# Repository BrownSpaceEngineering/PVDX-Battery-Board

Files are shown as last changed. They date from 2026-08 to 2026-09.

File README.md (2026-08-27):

# Battery-Board

Battery subsystem board for PVDX — connects the battery stack, solar cells/solar PCB, heaters, and thermistors.

## Status
- Design phase: fabrication
- Current rev: rev-1.1
- Contributors: Jayla Hsiung, Kelly Lin, Finn Kehoe, Dean Zweiman

## System overview

The Battery Board is primarily structural/routing rather than active. It has no onboard charging or regulation ICs (that logic lives on EPS). Its job is to tie the battery stack into the rest of the power subsystem: routing to the regular (non-perovskite) solar cells and solar PCB, driving the battery heaters, and carrying thermistor signals back for battery temperature monitoring.

**Board sheets:**

- **Heater**: battery heater circuit.
- **Connectors**: harness/pinout for battery, solar, heater, and thermistor connections. These are being hardwired rather than connectorized — the footprints (pad patterns) stay on the board for wire attachment points, but the 3D models are hidden (Show unchecked in Footprint Properties → 3D Models) so they don't appear in the STEP export.

### Repo layout

```
PVDX-Battery-Board/
├── PVDX-Battery-Board.kicad_pro / .kicad_sch / .kicad_pcb
├── fp-lib-table
├── schematics/
│   ├── heater.kicad_sch
│   └── connectors.kicad_sch
├── libs/
│   ├── footprints.pretty/
│   ├── symbols/
│   └── 3d_models/
└── manufacturing/
    └── rev-<N>_<date>/
        ├── gerbers/
        ├── bom/
        └── plots/
```

**Why hardwire instead of connectors:** simplifies the harness at the battery/heater interface and removes a failure point (connector) from a joint that doesn't need to be serviceable in flight. KiCad has no dedicated "exclude from STEP" option, so per-footprint 3D model visibility is the mechanism used to keep the pad pattern without the connector body in mechanical exports.

## Key design notes

- **Thermistor (NXFT15XV103FEAB025):** custom footprint, kept in `libs/footprints.pretty/`. The original vendor export had a stray space in the filename — fixed during the repo reorg.
- **Connector footprints, 3D models hidden:** see above — keep an eye on this after any "Update PCB from Schematic" footprint refresh, which can reset visibility to the library default and re-show the model.
- **`PVDX_BatteryBoard_Board.kicad_sch`** was an orphaned, blank sheet not referenced anywhere in the hierarchy — deleted during the reorg.

## Manufacturing history
| Rev | Date | Notes | Location |
|-----|---|---|---|
| 1.1 | 8/22/26 | Current gerber set | `manufacturing/rev-1.1_2026-08-22/` |

## Open items
- Fill in BOM for rev-1.1 (`manufacturing/rev-1.1_2026-08-22/bom/` currently empty)

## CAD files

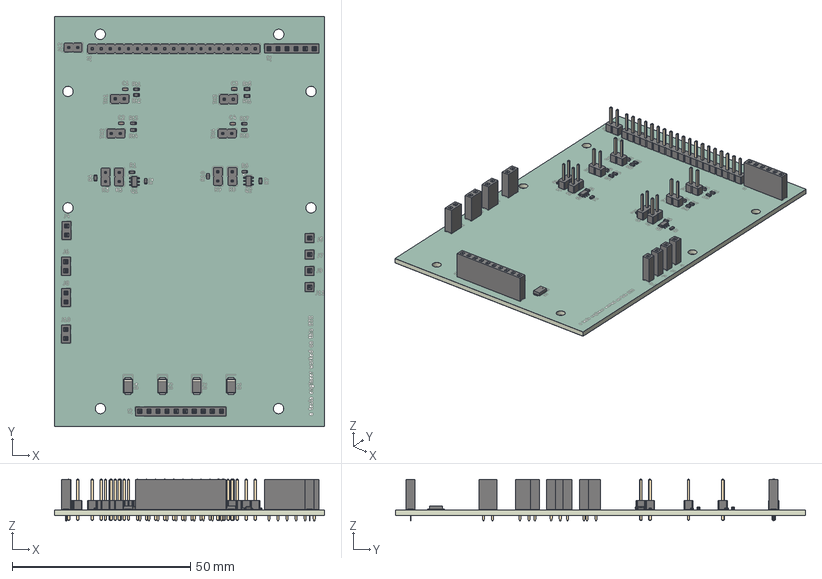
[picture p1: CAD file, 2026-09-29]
PVDX-Battery-Board.step
75.7 x 115.0 x 11.6 mm
R_0603_1608Metric x 14
PinSocket_1x01_P2.54mm_Vertical x 4
C_0603_1608Metric x 4
PinHeader_1x02_P2.54mm_Vertical x 9
PinSocket_1x10_P2.54mm_Vertical
D_SOD-128 x 4
PinSocket_1x06_P2.54mm_Vertical
PinHeader_1x19_P2.54mm_Vertical
PinSocket_1x02_P2.54mm_Vertical x 4
TSOT-23-6 x 2
PVDX_BatteryBoard_silkscreen x 2
PVDX_BatteryBoard_soldermask x 2
PVDX_BatteryBoard_PCB

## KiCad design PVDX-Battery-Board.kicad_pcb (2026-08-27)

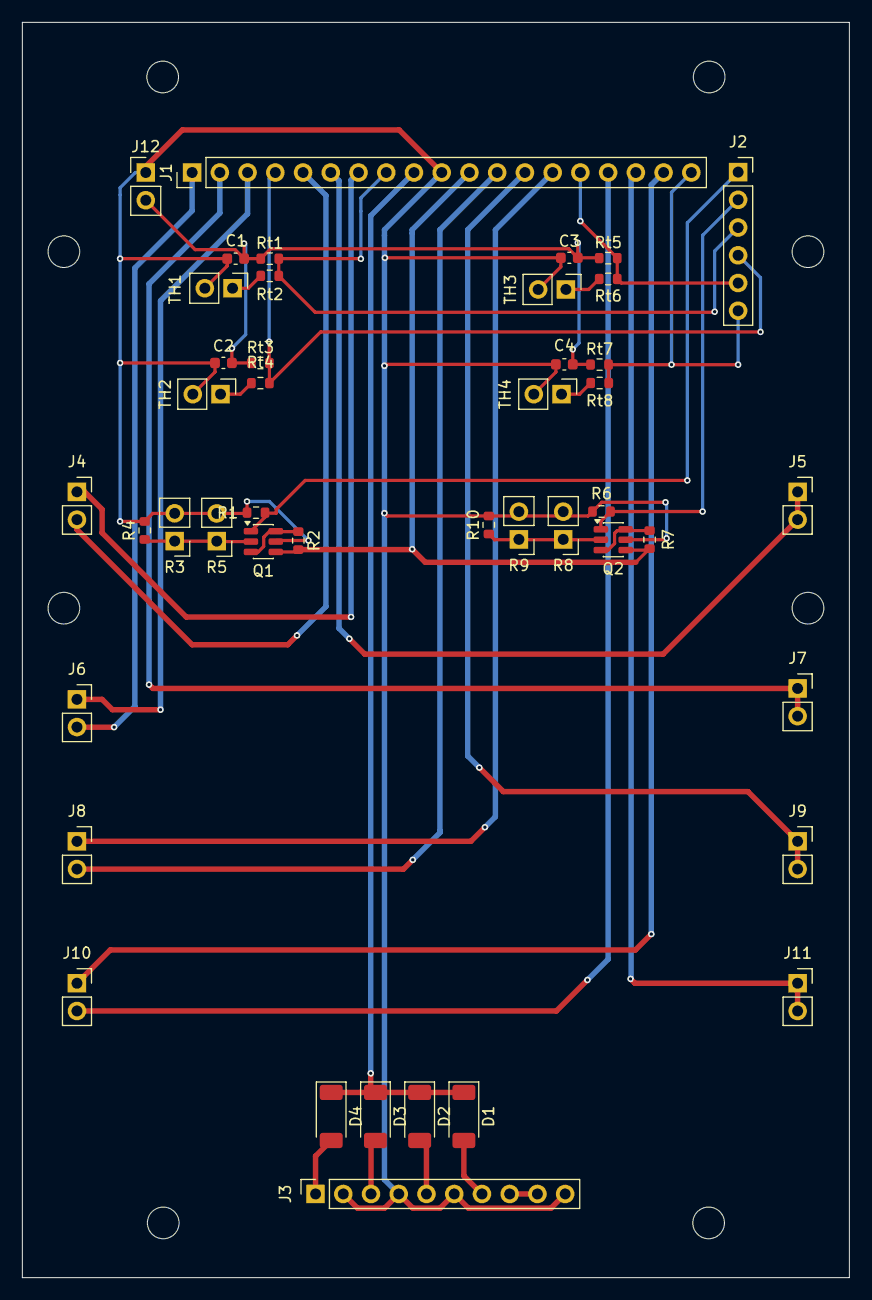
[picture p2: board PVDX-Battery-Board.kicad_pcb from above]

Board: 2 copper layers, 75.7 x 115.0 mm, 44 parts (0 on the bottom side), 35 nets.

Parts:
C1, C2, C3, C4: .1u; C_0603_1608Metric
D1, D2, D3, D4: D_Schottky; D_SOD-128
J1: Conn_01x19; PinHeader_1x19_P2.54mm_Vertical
J2: Conn_01x06; PinSocket_1x06_P2.54mm_Vertical
J3: Conn_01x10; PinSocket_1x10_P2.54mm_Vertical
J4, J5, J6, J7, J8, J9, J10, J11: Conn_01x02_Pin; PinSocket_1x02_P2.54mm_Vertical
J12: Conn_01x02; PinHeader_1x02_P2.54mm_Vertical
Q1, Q2: DMC2053UVT; TSOT-23-6
R1, R2, R4, R6, R7, R10: 10k; R_0603_1608Metric
R3, R5, R8, R9: Heater; PinHeader_1x02_P2.54mm_Vertical
Rt1, Rt3, Rt5, Rt7: 15.8k; R_0603_1608Metric
Rt2, Rt4, Rt6, Rt8: 5.83k; R_0603_1608Metric
TH1, TH2, TH3, TH4: GA10K3A1IA; PinHeader_1x02_P2.54mm_Vertical

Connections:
+5V: C1.1, C2.1, C3.1, C4.1, J12.2, Rt1.1, Rt3.1, Rt5.1, Rt7.1
BATT1+: J1.5, J4.2
BATT1-: J1.7, J4.1
BATT1M: J1.6, J5.1, J5.2
BATT2+: J1.1, J6.2
BATT2-: J1.3, J6.1
BATT2M: J1.2, J7.1, J7.2
BATT3+: J1.12, J8.2
BATT3-: J1.14, J8.1
BATT3M: J1.13, J9.1, J9.2
BATT4+: J1.16, J10.2
BATT4-: J1.18, J10.1
BATT4M: J1.17, J11.1, J11.2
CHG_OUT: J1.11, Q1.4 (D), Q2.4 (D), R2.1, R7.1
HEATER_ON_1: J2.1, Q1.1 (G), R1.1
HEATER_ON_2: J2.2, Q2.1 (G), R6.1
NTC1: J1.8, J2.3, Rt1.2, Rt2.1
NTC2: J1.4, J2.4, Rt3.2, Rt4.1
NTC3: J1.15, J2.5, Rt5.2, Rt6.1
NTC4: J1.19, J2.6, Rt7.2, Rt8.1
unnamed: Q1.3 (G), Q1.6 (D), R2.2
unnamed: Q1.2 (S), R3.1, R4.1, R5.1
unnamed: Q2.3 (G), Q2.6 (D), R7.2
unnamed: Q2.2 (S), R8.1, R9.1, R10.1
unnamed: Rt2.2, TH1.1
unnamed: Rt4.2, TH2.1
unnamed: Rt6.2, TH3.1
unnamed: Rt8.2, TH4.1
SOLAR: D1.1 (K), D2.1 (K), D3.1 (K), D4.1 (K), J1.9
SOLAR_1s: J3.8, J3.9
SOLAR_1s_GND: C1.2, C2.2, C3.2, C4.2, J1.10, J3.2, J3.4, J3.6, J3.10, J12.1, Q1.5 (S), Q2.5 (S), R1.2, R3.2, R4.2, R5.2, R6.2, R8.2, R9.2, R10.2, TH1.2, TH2.2, TH3.2, TH4.2
SOLAR_2s: D1.2 (A), J3.7
SOLAR_3s1: D4.2 (A), J3.1
SOLAR_3s2: D3.2 (A), J3.3
SOLAR_3s3: D2.2 (A), J3.5

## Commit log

2026-04-28 added heater schematic
    [PVDX_BatteryBoard.kicad_sch, PVDX_BatteryBoard_Board.kicad_sch, PVDX_BatteryBoard_Heater.kicad_sch]
2026-05-01 added solar connectors schematic
    [PVDX_BatteryBoard_Board.kicad_sch]
2026-05-03 added second heater to heater schematic
    [PVDX_BatteryBoard_Heater.kicad_sch]
2026-08-03 Finish battery board schematic (awaiting thermistor part no.)
    [PVDX_BatteryBoard.kicad_sch, PVDX_BatteryBoard_Board.kicad_sch, PVDX_BatteryBoard_Heater.kicad_sch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]
2026-08-08 Add thermistor & MOSFET parts/values
    [PVDX_BatteryBoard.kicad_sch, PVDX_BatteryBoard_Heater.kicad_sch, PVDX_BatteryBoard_connectors.kicad_sch]
2026-08-16 finished routing
    [PVDX_BatteryBoard.kicad_pcb, PVDX_BatteryBoard.kicad_sch, PVDX_BatteryBoard_Heater.kicad_sch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]
2026-08-21 Add screw holes, make battery pack mid 2 holes
    [PVDX_BatteryBoard.kicad_pcb, PVDX_BatteryBoard_connectors.kicad_sch]
2026-08-22 Add gerber files
    [PVDX_BatteryBoard-B_Cu.gbr, PVDX_BatteryBoard-B_Mask.gbr, PVDX_BatteryBoard-B_Paste.gbr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]
2026-08-22 Fix routing, regenerate gerbers
    [PVDX_BatteryBoard-B_Cu.gbr, PVDX_BatteryBoard-B_Mask.gbr, PVDX_BatteryBoard-B_Paste.gbr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]
2026-08-27 reorg: rename project PVDX_BatteryBoard -> PVDX-Battery-Board, consolidate libs/, move aux sheets to schematics/, structure manufacturing/rev-1.1_2026-08-22/, remove orphaned Board.kicad_sch, add git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
    [PVDX-Battery-Board-B_Cu.gbr, PVDX-Battery-Board-B_Mask.gbr, PVDX-Battery-Board-B_Paste.gbr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]
2026-08-27 generate STEP, fix 3dmodels
    [PVDX-Battery-Board.kicad_pcb, PVDX-Battery-Board.step]
2026-09-25 spaced out diodes more, added some planes for solar net
    [PVDX_BatteryBoard.kicad_pcb]
2026-09-26 updated board and designed reviewed by my coworkers
    [PVDX-Battery-Board.kicad_sch, PVDX_BatteryBoard.kicad_pcb, connectors.kicad_sch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]
2026-09-29 regen STEP
    [PVDX-Battery-Board.step]
2026-10-14 Add battery overdischarge & short protections to board
